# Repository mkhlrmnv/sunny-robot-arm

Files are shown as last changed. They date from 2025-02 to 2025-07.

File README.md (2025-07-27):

# Sunny Robot Arm 🌞🤖

The project is built by Mikhail Romanov and Jaakko Aalto completely from scratch. Only motors, drivers, linear rail and arms aluminum profile were bought, all the rest is custom made by first designing parts in CAD, then manufacturing them using multiple metalworking techniques like CNC milling, water cutting and metal turning or 3D printing for smaller parts.

Project is a precision solar tracking robotic arm system that automatically follows the sun's path throughout the day. This 2-DOF robotic arm mounted on a linear rail uses advanced kinematics calculations to track solar positions while maintaining safety through collision detection. At the end arm has RGB LED lamp that ajust its brightness and color based on the solar position and system status. This features allow robot to simulate effect of the sunlight on office enviroment, which is then used in the Aalto University research to study the impact of natural light on human well-being and productivity in house automation and smart buildings.

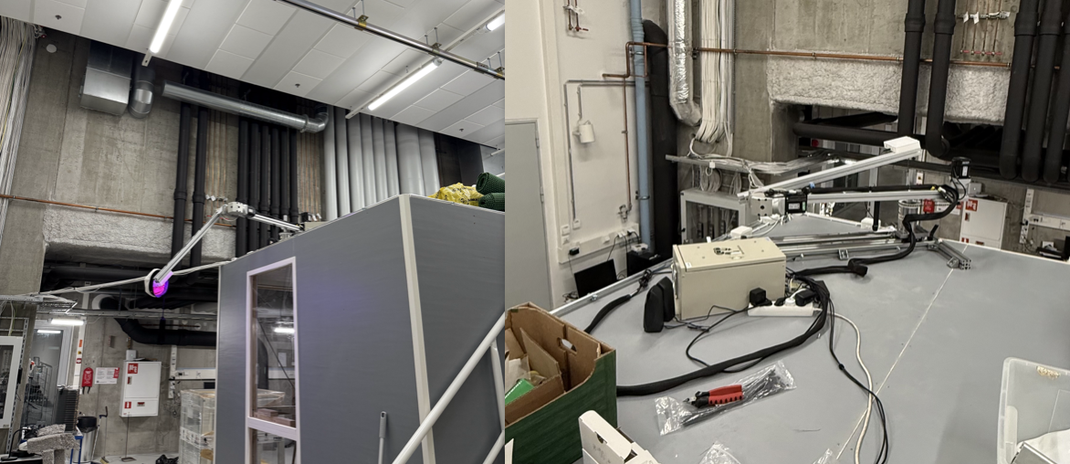
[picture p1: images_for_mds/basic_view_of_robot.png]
Basic view of the robot


### Web Dashboard Features

- Real-time 3D robot visualization while executing pathits brightness and color based on the solar position and system status. This features allow robot to simulate effect of the sunlight on office enviroment, which is then used in the Aalto University research to study the impact of natural light on human well-being and productivity in house automation and smart buildings.

## 🌟 Features

- **Automated Solar Tracking**: Follows the sun's path automatically using astronomical calculations
- **Smart RGB LED Lamp**: WLED-controlled end effector with dynamic color and brightness that can be controlled via web browser, mobile app, or automatically synchronized with robot movements
- **Precise Kinematics**: Forward and inverse kinematics for accurate positioning
- **Safety Systems**: Built-in collision detection and safety boundary enforcement
- **Web Interface**: Real-time control and monitoring via Flask web application
- **Multi-Location Support**: Pre-configured solar paths for Finland and Singapore
- **Warning System**: Warning system with visual and audio alerts
- **Temperature Management**: Automatic cooling system with fan control
- **Manual Control**: Direct motor control for testing and calibration

## 🏗️ Hardware Architecture

### Robotic Arm Components
- **Pontto Joint**: Base rotation motor (spinning joint) controlling the yaw angle
- **Paaty Joint**: Pitch/elevation motor (spinning joint) controlling the pitch angle
- **Linear Rail**: Horizontal positioning system
- **LED Strip**: End effector with RGB LED lamp for visual status feedback via WLED (controllable via web browser, mobile app, or automatically synchronized with robot movements)
- **Cooling Fan**: Temperature management system
- **Limit Switches and Induction Sensors**: Safety and homing sensors

### Technical Specifications
- **Arm lengths**: 
  - Pontto: 835mm
  - Paaty: 905mm
- **Rail Travel**: 731.3mm linear range
- **Joint Angles**: 
  - Pontto: -172° to +188° (360° range)
  - Paaty: ±180° range
- **Precision**: Stepper motor control with gear ratios

## 📁 Project Structure

```
sunny-robot-arm/
├── src/                          # Core application code
│   ├── arm.py                    # Main robot arm controller
│   ├── kinematics_and_safety.py  # Forward/inverse kinematics & collision detection
│   ├── sun_helper.py             # Solar position calculations
│   ├── spinning_joints.py        # Rotational motor control
│   ├── linear_rail.py            # Linear actuator control
│   ├── lamp.py                   # LED control interface
│   ├── cooling.py                # Temperature management
│   └── config.py                 # Hardware configuration constants
│   └── warning.py                # Warning system for audio alerts
├── ui/                           # Web interface
│   ├── main.py                   # Flask web server
│   ├── templates/                # HTML templates
│   └── static/                   # CSS/JS assets
├── paths/                        # Pre-calculated solar paths
├── test/                         # Unit tests
├── documentation/                # Technical documentation
└── sounds/                       # Audio feedback files
```

## 🚀 Quick Start

### Were to start

- **Basic Guide** Basic tutorial on how to use the robot via web interface or API, refer to the tutorial md [here](quick_tutorial.md).
- **Documentation**: Detailed documentation in strucuture of the robot (electrical wirings, class structure, manufacturing process, etc.) can be found in the [documentation](documentation/README.md).

### Hardware used in this project
- Raspberry Pi 4
- Python 3.10
- 2x JT-RD6012 Power Supply (70v x 12.5A)
- 3x Leadshine CS-M23445 stepper motors with Leadshine CS-D808 drivers
- WLED-compatible LED strip (with 144 LEDs/m)
- 2x SN04-N Induction Sensors for homing
- 2x Basic limit switches for linear rail position detection
- A lot other unspecified parts like fan, power supplies and thermal sensor that can be found in wiring diagram

### Cooling System

Automatic temperature management with configurable thresholds:

- Fan activation at 30°C
- Maximum cooling at 60°C
- Temperature logging and alerts

## 📄 License

This project is licensed under the MIT License - see the [LICENSE](LICENSE) file for details.

## 🙏 Acknowledgments

- **pvlib**: Solar position calculations
- **Flask**: Web interface framework  
- **NumPy/SciPy**: Mathematical computations
- **Matplotlib**: Visualization tools
- **RPi.GPIO**: Raspberry Pi hardware control

---

**Built with ❤️ and passion for robotics**

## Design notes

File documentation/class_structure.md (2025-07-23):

# Sunny Robot Arm - Class Structure

## 🏗️ Core Architecture Overview

The project follows a modular architecture with clear separation of concerns:

```
Main Controller (Arm) 
    ├── Motor Controllers (SpinningJoints, LinearRail)
    ├── Visual Feedback (Lamp)  
    ├── Audio System (WarningSound)
    ├── Kinematics Engine (Functions)
    ├── Safety Systems (Functions)
    └── Cooling System (FanController)
```

## 📋 Class Diagram

### 🎮 **Main Controller Classes**

#### **`Arm`** - Primary Robot Controller
```python
class Arm:
    # Properties
    - theta_1: float              # Pontto joint angle (°)
    - theta_2: float              # Paaty joint angle (°) 
    - delta_r: float              # Linear rail position (mm)
    - required_theta_1: float     # Target pontto angle
    - required_theta_2: float     # Target paaty angle
    - required_delta_r: float     # Target rail position
    - current_path: np.array      # Path points to follow
    - current_path_colors: list   # Color data for path visualization
    - iteration: int              # Current path point index
    - duration_per_point: float   # Time per path point
    - shared: Namespace           # Multiprocessing shared state
    
    # Component References
    - motor_paaty: SpinningJoints     # Pitch motor controller
    - motor_pontto: SpinningJoints    # Yaw motor controller  
    - motor_rail: LinearRail          # Linear actuator controller
    - lamp: Lamp                      # LED strip controller
    - warning_sound: WarningSound     # Audio feedback system
    
    # Methods
    + __init__(shared, init_pos, dimensions...)
    + init()                          # Initialize and home all motors
    + shutdown()                      # Safe shutdown procedure
    + init_path(path_file, duration)  # Load solar tracking path
    + move(speeds, check_safety)      # Execute movement to next path point
    + _target_not_set() -> bool       # Check if target is defined
    + _step_towards(attr, target)     # Safe incremental movement
    + _compute_next_target()          # Calculate next path target
    + _clear_target()                 # Reset target after reaching point
    + draw_all(index, ax)             # Visualization for matplotlib
```

### 🔧 **Motor Controller Classes**

#### **`SpinningJoints`** - Rotational Motor Controller
```python
class SpinningJoints:
    # Properties
    - shared: Namespace           # Multiprocessing shared state
    - name: str                   # Motor identifier ("pontto"/"paaty")
    - angle: float                # Current angle (degrees)
    - steps: int                  # Step count from home position
    - step_per_rev: int           # Steps per motor revolution (1600)
    - gear_ratio: float           # Gearbox reduction ratio
    - angle_limit: float          # Maximum rotation range
    - min_delay: float            # Fastest step timing
    - max_delay: float            # Slowest step timing
    
    # Hardware Interfaces
    - pulse: DigitalOutputDevice  # Step pulse pin
    - direction: DigitalOutputDevice  # Direction control pin
    - limit_switch: Button        # Homing sensor
    - limit_event: Event          # Thread-safe sensor state
    
    # Methods
    + __init__(shared, pins, name, ratios...)
    + init_motor(speed)           # Homing sequence with sensor detection
    + step(direction, speed)      # Single step execution
    + move_by_angle(angle, speed) # Relative angular movement
    + move_to_angle(angle, speed) # Absolute angular positioning
    + calc_delay(speed_percent)   # Speed-to-timing conversion
    + reset_position()            # Set current position as zero
    + shutdown()                  # Safe parking position
```

#### **`LinearRail`** - Linear Actuator Controller  
```python
class LinearRail:
    # Properties
    - shared: Namespace           # Multiprocessing shared state
    - distance: float             # Current position (mm)
    - steps: int                  # Step count from home
    - angle: float                # Equivalent angular displacement
    - step_per_rev: int           # Motor steps per revolution
    - gear_ratio: float           # Gear reduction factor
    - pitch: float                # Lead screw pitch (mm/rev)
    - min_delay: float            # Timing limits for speed control
    - max_delay: float
    - stop: bool                  # Limit switch state
    
    # Hardware Interfaces  
    - pulse: DigitalOutputDevice  # Step pulse pin
    - direction: DigitalOutputDevice  # Direction control pin
    - limit_switch: Button        # Position limit sensor
    - limit_event: Event          # Thread-safe limit state
    
    # Methods
    + __init__(shared, pins, mechanical_params...)
    + init_motor(direction)       # Homing to limit switch
    + step(direction, speed, ignore_limit)  # Single step with safety
    + move_by_distance(dist, speed)         # Relative linear movement
    + move_to_distance(dist, speed)         # Absolute positioning
    + calc_delay(speed_percent)             # Speed mapping
    + reset_position()                      # Zero position reference
```

### 🎨 **Feedback Systems**

#### **`Lamp`** - RGB LED Controller
```python
class Lamp:
    # Properties
    - brightness: int             # Overall brightness (0-255)
    - https_url: str              # WLED controller URL
    - red: int                    # Current red component (0-255)
    - green: int                  # Current green component (0-255) 
    - blue: int                   # Current blue component (0-255)
    - effect: int                 # WLED effect index (0=solid, 1=blink...)
    - speed: int                  # Effect speed (milliseconds)
    
    # Methods
    + __init__(brightness, https_url)
    + set_brightness(level)       # Control overall brightness
    + set_to_effect(r, g, b, effect, speed)  # Generic effect control
    + set_to_solid(r, g, b)       # Solid color mode
    + set_to_blink(r, g, b, speed)           # Blinking warning mode
    + _send_to_wled(json_data)               # HTTP API communication
```

#### **`WarningSound`** - Audio Alert System
```python
class WarningSound:
    # Properties
    - _stop: threading.Event      # Thread synchronization
    - _thread: Thread             # Background playback thread
    - _is_playing: bool           # Current playback state
    
    # Methods
    + __init__(audio_file)        # Load sound file via pygame
    + start()                     # Begin looped playback
    + stop()                      # Stop playback and cleanup
    + _play_loop()                # Internal playback thread
```

#### **`FanController`** - Thermal Management
```python
class FanController:
    # Properties
    - sensor: W1ThermSensor       # DS18B20 temperature sensor
    - fan: PWMOutputDevice        # PWM-controlled cooling fan
    - min_temp: float             # Fan activation threshold (°C)
    - max_temp: float             # Full-speed threshold (°C)
    - latest_reading: dict        # Current temperature/speed data
    
    # Methods
    + __init__(fan_pin, min_temp, max_temp)
    + map_temp_to_speed(temp)     # Temperature to PWM conversion
    + run(verbal, interval)       # Main control loop
    + shutdown()                  # Safe fan stop and GPIO cleanup
```

### 🧮 **Utility Functions** (Functional Programming)

#### **Kinematics Module** (`kinematics_and_safety.py`)
```python
# Core Kinematics Functions
+ inverse_kinematics(x, y, z, **params) -> List[Tuple[float, float, float]]
    # Solve joint angles for target position
    
+ forward_kinematics(theta1, theta2, delta_r, **params) -> np.array
    # Calculate all joint positions from angles
    
+ choose_solution(solutions, current_state) -> Tuple[float, float, float]
    # Select optimal solution from IK candidates

# Safety and Collision Detection
+ check_solutions_safety(solution, safety_boxes) -> bool
    # Verify movement doesn't cause collisions
    
+ draw_robot(ax, points) -> None
    # 3D visualization of robot configuration
    
+ draw_all_safety_boxes(ax) -> None
    # Render collision boundaries
```

#### **Solar Path Module** (`sun_helper.py`)
```python
# Solar Position Calculations
+ get_sun_path_finland(R, lat, lon, timezone) -> Tuple[np.array, np.array, np.array]
    # Generate solar tracking path for Finland
    
+ get_sun_path_singapore(R, lat, lon, timezone) -> Tuple[np.array, np.array, np.array]
    # Generate solar tracking path for Singapore
    
+ alt_to_color(altitude_deg) -> Tuple[int, int, int]
    # Map solar altitude to RGB color temperature
    
+ jsonify_path(path, colors, filename) -> None
    # Serialize path data to JSON
    
+ un_jsonify_path(filename) -> Tuple[np.array, np.array]
    # Load path data from JSON
```

### 🌐 **Web Interface** (`ui/main.py`)

#### **Flask Application**
```python
# Global State
- app: Flask                      # Web server instance
- arm: Arm                        # Robot controller reference
- shared: Namespace               # Multiprocessing shared state
- motor_lock: Lock                # Thread synchronization
- angles_per_key: int             # Manual control step size

# Core Routes
@app.route('/')                   # Main dashboard
@app.route('/manual')             # Manual control interface
@app.route('/move_arm')           # Primary API endpoint
@app.route('/points')             # Current robot position data
@app.route('/path_points')        # Active path visualization data  
@app.route('/cooling_info')       # Temperature monitoring

# Process Management Functions
+ start_arm(func, args)           # Execute robot function in subprocess
+ stop_arm()                      # Terminate active robot processes
+ is_arm_running() -> bool        # Check subprocess status
+ start_arm_and_wait(func, args) -> int  # Blocking execution with return code
```

## 🔄 **Data Flow Architecture**

### **Multiprocessing Communication**
```python
# Shared State Object (Manager.Namespace)
shared = {
    'theta_1': float,        # Current pontto angle
    'theta_2': float,        # Current paaty angle  
    'delta_r': float,        # Current rail position
    'path_it': int,          # Path iteration counter
    'timer': float,          # Last movement timestamp
    'path': np.array         # Active path points
}
```

### **Control Flow**
1. **Web Interface** receives user commands
2. **Flask API** validates parameters and safety
3. **Process Manager** spawns subprocess for robot control
4. **Arm Controller** coordinates motor movements
5. **Motor Controllers** execute precise positioning
6. **Feedback Systems** provide visual/audio status
7. **Shared State** maintains synchronization across processes

### **Safety Integration**
- All movements validated through **inverse kinematics**
- **Collision detection** prevents unsafe configurations
- **Joint limits** enforced at motor controller level
- **Emergency stop** capability via web interface
- **Homing sequences** ensure accurate position reference

## 📊 **Key Design Patterns**

### **Composition over Inheritance**
- `Arm` class aggregates motor controllers rather than inheriting
- Enables flexible configuration and testing
- Clear component boundaries and responsibilities

### **Shared State Pattern**  
- `multiprocessing.Manager.Namespace` for inter-process communication
- Thread-safe access to robot state across web server and control processes

### **Observer Pattern**
- GPIO limit switches trigger events for safety monitoring
- Real-time status updates to web interface

This architecture provides a robust, safe, and extensible foundation for precise solar tracking while maintaining clear separation between hardware control, safety systems, and user interfaces.

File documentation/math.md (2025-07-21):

# Explanations of the math used in this project

## Link to the notebook
You can find the explanations of the math used in this project in the following notebook:
[GoodNotes Notebook](https://share.goodnotes.com/s/Pw0ZdXbuqwoWTpLTJgBrya)

## Catalog of the notebook
- **Config**: This sections explains variables used in the project, such as names of the specific parts of the robot.
- **Forward Kinematics**: This function calculates the position and orientation of the all 6 points of the arm based on the joint angles.
- **Inverse Kinematics**: This function calculates the joint angles required to reach a specific position in space.
- **Get Suns Position**: This function calculates the position of the sun based on the provided time and date and adjust all the points to be reachable by the arm.

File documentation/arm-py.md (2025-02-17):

### Explanation of `calc_join_angles` Function

The `calc_join_angles` function calculates the joint angles (`theta1` and `theta2`) for a robotic arm based on the desired position (`pos`). The function assumes that the robotic arm has two segments (`arm1` and `arm2`) and calculates the angles required to reach the given position.

#### Calculations

#### Theta2 Calculation

1. **Calculate the difference in the z-axis (`delta_z`)**:
    ```python
    delta_z = self.base_pos.z - pos.z
    ```

2. **Calculate the horizontal distance ([alpha](http://_vscodecontentref_/0))**:
    ```python
    alpha = np.sqrt(self.arm2_length**2 - delta_z**2)
    ```

3. **Calculate the angle [theta3](http://_vscodecontentref_/1)**:
    ```python
    theta3 = np.arccos(delta_z / self.arm2_length)
    ```

4. **Calculate the angle [theta2](http://_vscodecontentref_/2)**:
    ```python
    theta2 = theta3 + np.deg2rad(90)
    ```

### Theta1 Calculation

1. **Calculate the difference in the y-axis ([delta_y](http://_vscodecontentref_/3))**:
    ```python
    delta_y = self.base_pos.y - pos.y
    ```

2. **Calculate the angle [theta1](http://_vscodecontentref_/4)**:
    ```python
    theta1 = np.arccos(delta_y / (self.arm1_length + alpha))
    ```

#### Return Value

The function returns a tuple containing the calculated angles ([theta1](http://_vscodecontentref_/5) and [theta2](http://_vscodecontentref_/6)):
```python
return (theta1, theta2)
```

#### Description on paper
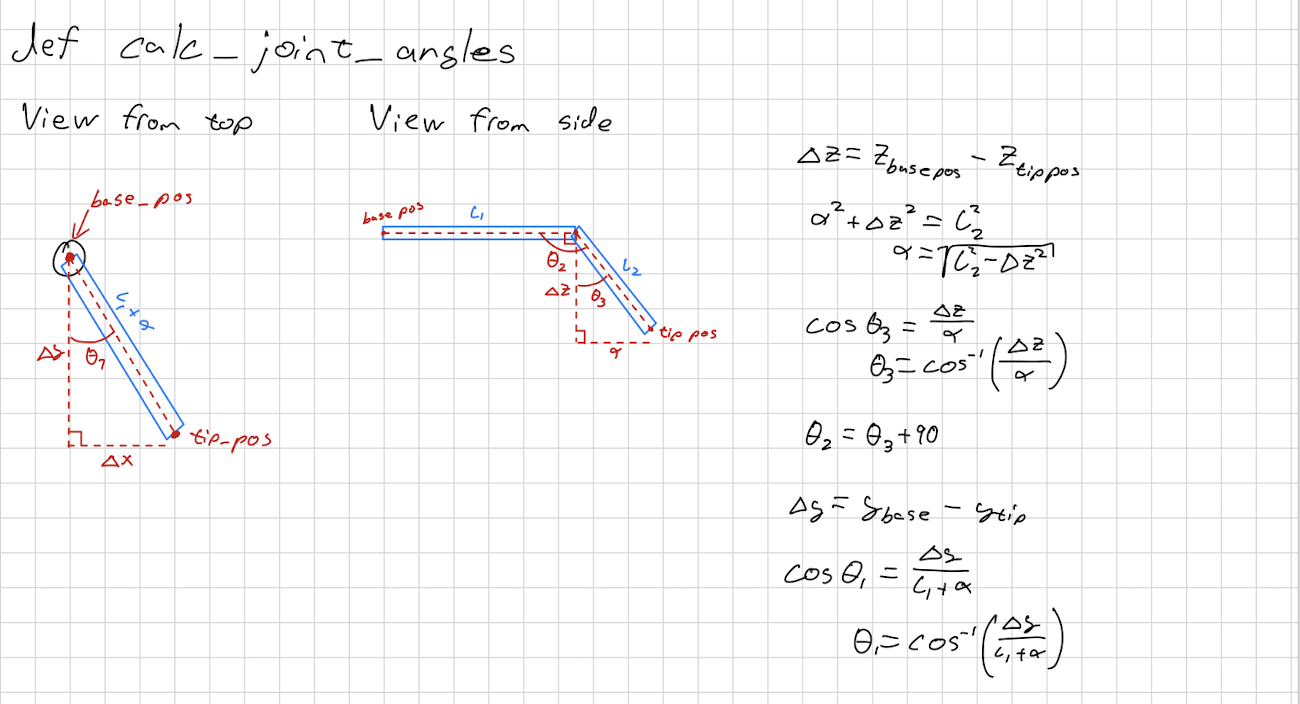
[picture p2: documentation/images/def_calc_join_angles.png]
Description of the image


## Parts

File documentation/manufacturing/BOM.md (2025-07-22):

# Bill of Materials

This project uses the following components:

| Part | Quantity | Link |
|---|---|---|
| Switching power supply Joy-IT JT-RD6012-NT (56–71V, 12.5A) | 2 | [link](https://www.rocketronics.de/shop/en/JT-RD6012-NT.html) |
| Driveset 1-axis with CS-D808 and 4.5Nm closed loop motor CS-M23445 | 3 | [link](https://www.rocketronics.de/shop/en/product_info.php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) |
| EG Series Planetary Gearbox (5:1, 15 arc-min, for Nema 34) | 2 | [link](https://www.omc-stepperonline.com/eg-series-planetary-gearbox-gear-ratio-5-1-backlash-15-arc-min-for-nema-34-stepper-motor-eg34-g5) |
| RYG Series Right Angle Planetary Gearbox (5:1, 10 arc-min, for Nema 34) | 1 | [link](https://www.omc-stepperonline.com/ryg-series-right-angle-planetary-gearbox-gear-ratio-5-1-backlash-10arc-min-for-nema-34-stepper-motor-ryg34-g5) |
| Raspberry Pi 5 | 1 | [link](https://www.power.fi/tietotekniikka/tietokonekomponentit/mikrokontrollerit/raspberry-pi-5-4-gt-yhden-piirilevyn-tietokone/p-3325901/) |
| Raspberry Pi power supply | 1 | [link](https://www.power.fi/tietotekniikka/tietokonekomponentit/mikrokontrollerit/raspberry-pi-5-virtalahde/p-3325903/) |
| Machined ballscrew SFU2010–1500mm with nut | 1 | [link](https://greenlab.fi/tuote/tyostetty-kuularuuvi-sfu2010-1500mm-mutterilla/) |
| Ballscrew support bearing BK15 | 1 | [link](https://greenlab.fi/tuote/kuularuuvin-tukilaakeri-bk15/) |
| Ballscrew support bearing BF15 | 1 | [link](https://greenlab.fi/tuote/kuularuuvin-tukilaakeri-bf15/) |
| Ballnut housing DSG20H | 1 | *(no link provided)* |
| Aluminium profile 45×45 L, 1m | 1 | [link](https://greenlab.fi/tuote/alumiiniprofiili-45x45-l/) |
| Aluminium profile 45×45 light, 1m | 1 | [link](https://greenlab.fi/tuote/alumiiniprofiili-45x45-kevyt/) |
| Linear rail HGR25R-C (1m) | 2 | [link](https://greenlab.fi/tuote/lineaarijohde-hgr25r-c/) |
| Linear block HGW25HA Z0C | 2 | [link](https://greenlab.fi/tuote/lineaarikelkka-hgw25ha-z0c/) |
| Rail end stopper HG25 | 4 | [link](https://greenlab.fi/tuote/pysaytinpaaty-hg25/) |
| Jaw coupling MM2 40 D14/12 | 1 | [link](https://greenlab.fi/tuote/sakarakytkin-mm2-40-d14-17/) |

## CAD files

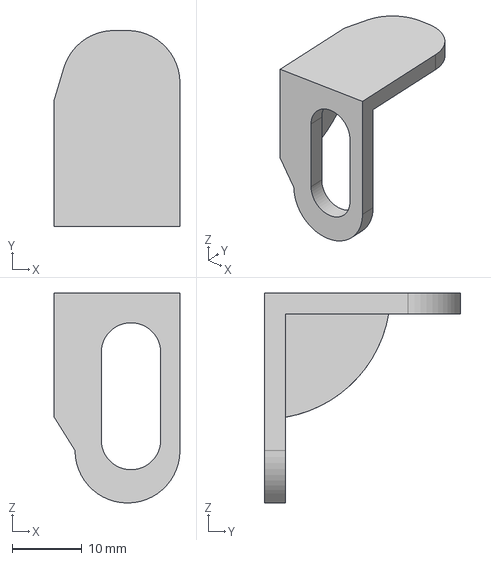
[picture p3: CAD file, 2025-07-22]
documentation/manufacturing/Corner safeguard.step
18.0 x 28.0 x 30.0 mm

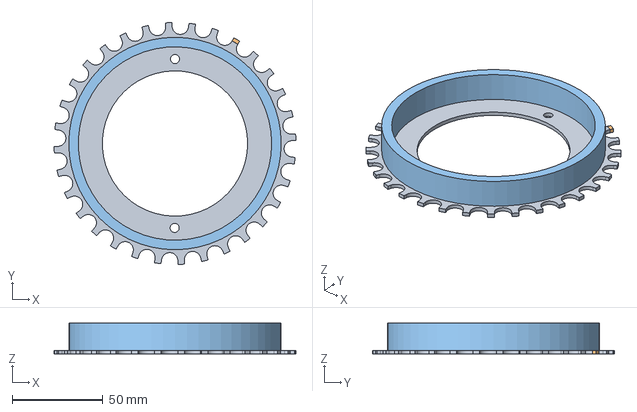
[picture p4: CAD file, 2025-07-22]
documentation/manufacturing/Gears/Big gear.step
133.3 x 133.3 x 17.0 mm

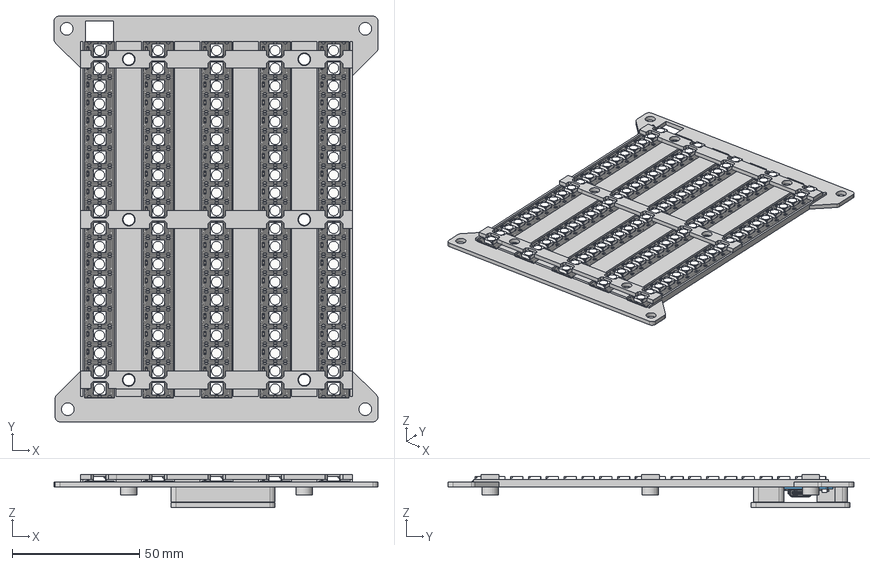
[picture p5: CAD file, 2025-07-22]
documentation/manufacturing/Lamp/STL files/LED base (base).step
127.3 x 159.5 x 13.0 mm
SMD x 100
WS2812 LED Chip x 100
PCB Strip x 100
Pads x 100
esp kansi
USB C + USB A 3.1.stp
main board
palkki x 3

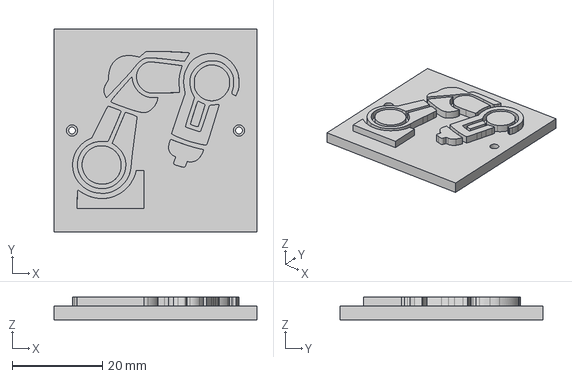
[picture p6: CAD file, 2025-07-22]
documentation/manufacturing/Logos/logo positive.step
45.0 x 45.0 x 5.00 mm

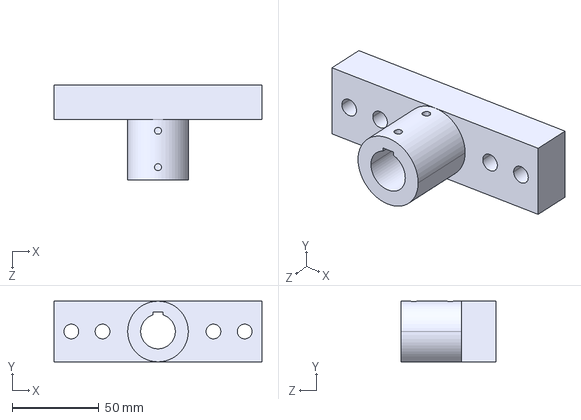
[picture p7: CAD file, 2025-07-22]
documentation/manufacturing/Motor attachers/Bevel gear attacher (to greenlab profile).STEP
120.0 x 35.0 x 55.0 mm

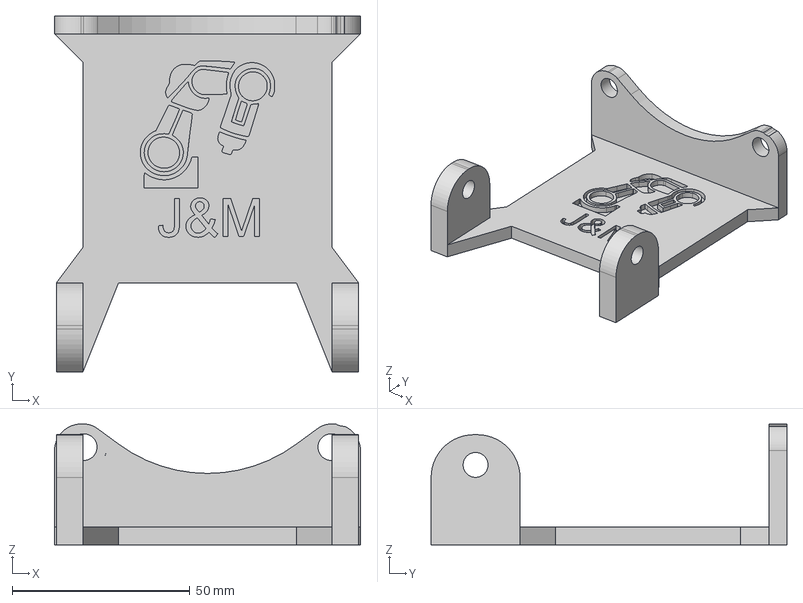
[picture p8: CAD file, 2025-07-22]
documentation/manufacturing/Motor attachers/Linear motor/Linear motor connector to robot's base.step
86.0 x 100.0 x 34.0 mm

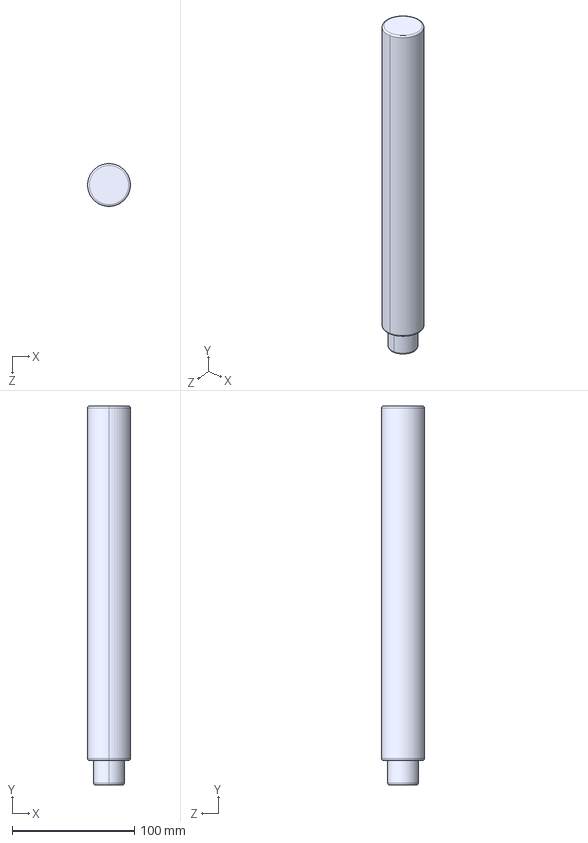
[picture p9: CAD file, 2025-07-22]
documentation/manufacturing/Pönttö parts/Axis of rotation.STEP
35.0 x 310.0 x 35.0 mm

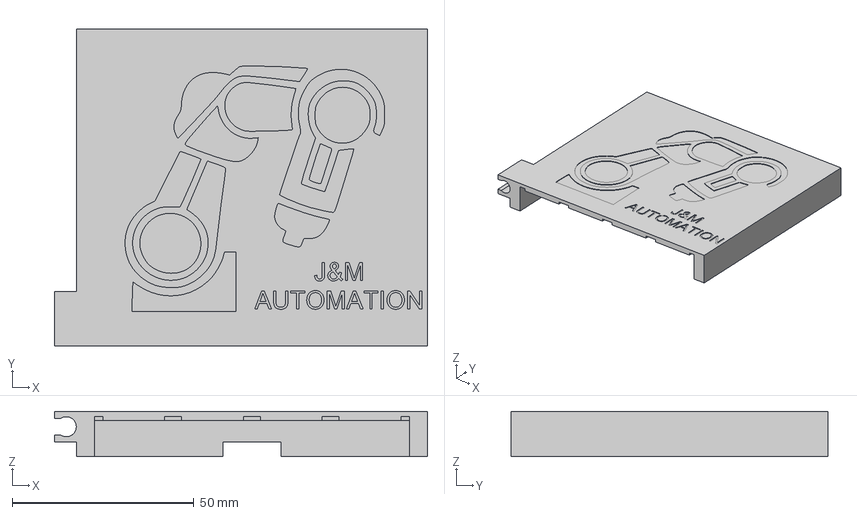
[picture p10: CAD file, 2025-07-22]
documentation/manufacturing/Random holders/Box for USB extension cabse (cover).step
102.7 x 87.2 x 12.5 mm

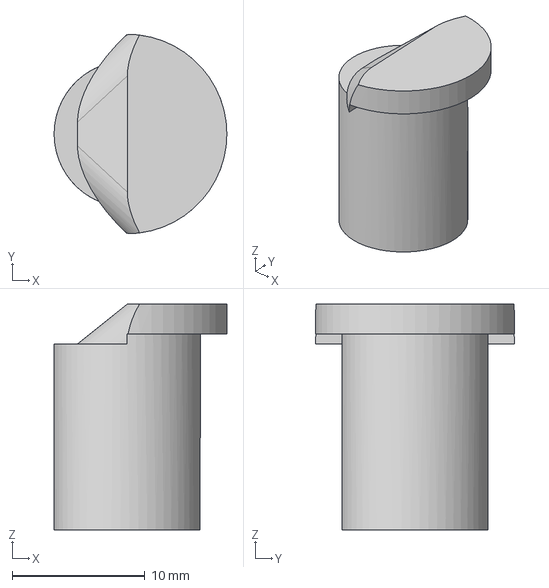
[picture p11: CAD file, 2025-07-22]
documentation/manufacturing/Sensors/Linear init/Pin for limit switch holder.step
13.0 x 15.0 x 17.0 mm

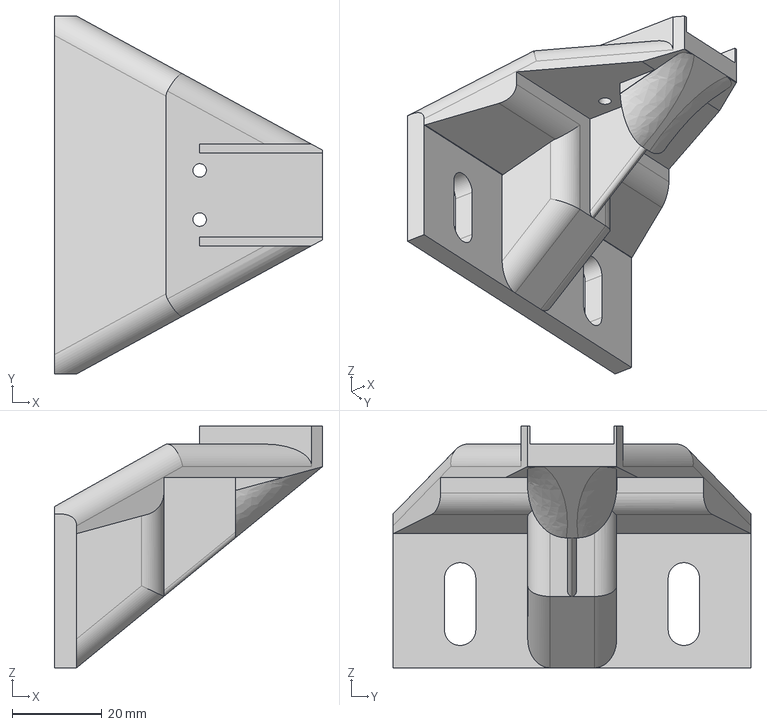
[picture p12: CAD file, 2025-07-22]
documentation/manufacturing/Sensors/Paaty init/Paaty motor init sensor holder.step
60.0 x 80.0 x 54.0 mm

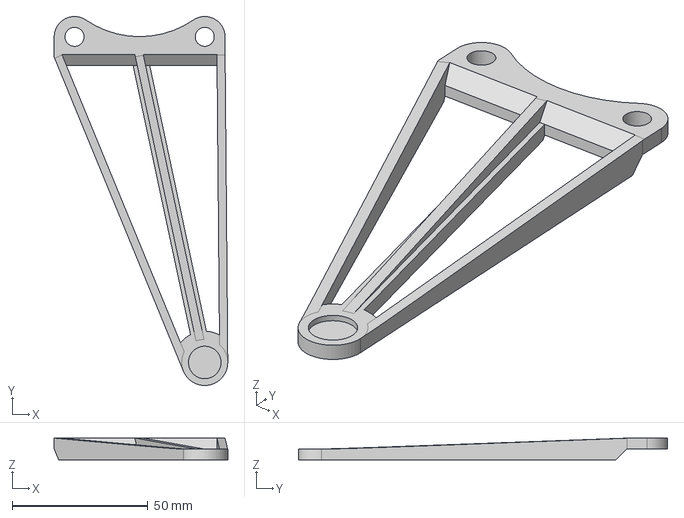
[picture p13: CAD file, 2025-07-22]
documentation/manufacturing/Sensors/Pontto init/Melta holder for pontto motor init.step
64.0 x 136.0 x 8.00 mm

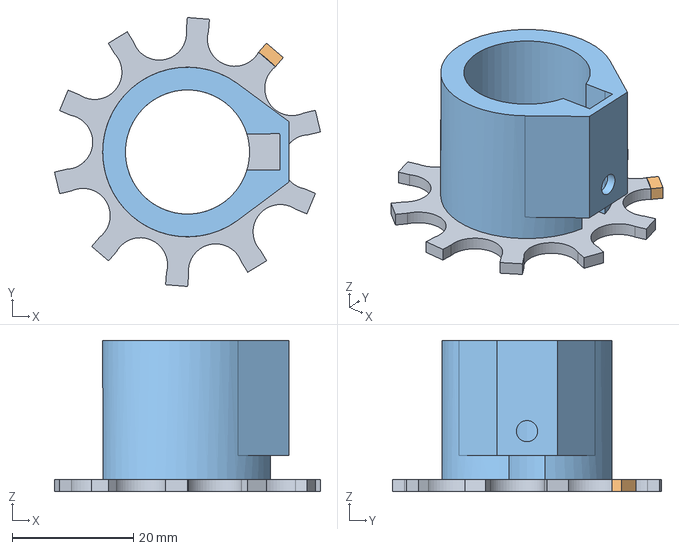
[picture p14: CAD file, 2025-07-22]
documentation/manufacturing/Gears/Small gear.step
43.9 x 44.4 x 25.0 mm

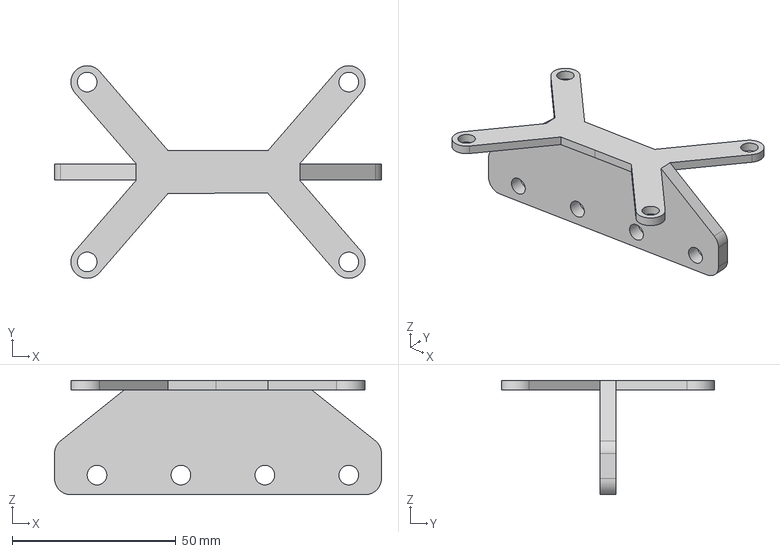
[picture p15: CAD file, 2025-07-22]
documentation/manufacturing/Lamp/STL files/Lamp attacher (general).step
100.0 x 65.0 x 35.0 mm
yleinen pidike

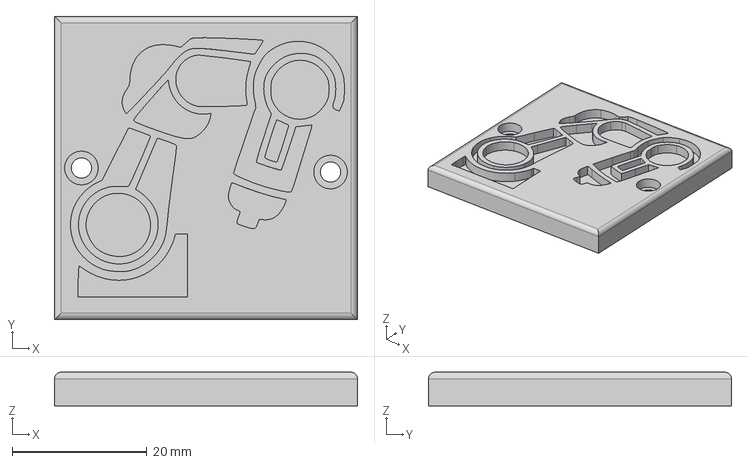
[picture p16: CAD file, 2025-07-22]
documentation/manufacturing/Logos/logo negative.step
45.0 x 45.0 x 5.00 mm

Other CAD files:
documentation/manufacturing/Motor attachers/Direct gear attacher (to greenlab profile).STEP
documentation/manufacturing/Motor attachers/Linear motor/Linear motor holder.SLDPRT
documentation/manufacturing/Original idea.step
documentation/manufacturing/Pönttö parts/Base pipe.STEP
documentation/manufacturing/Corner safeguard.f3d
documentation/manufacturing/Gears/Big gear.f3d
documentation/manufacturing/Gears/Small gear.f3d
documentation/manufacturing/Lamp/LED strip base.f3z
documentation/manufacturing/Lamp/STL files/Base box of the lamp.step
documentation/manufacturing/Lamp/STL files/Cover of the lamp.step
documentation/manufacturing/Lamp/STL files/LED base (esp cover).step
documentation/manufacturing/Lamp/STL files/LED base (holder piece).step
documentation/manufacturing/Lamp/STL files/Lamp attacher (greenlab profile).step
documentation/manufacturing/Logos/logo negative.f3d
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

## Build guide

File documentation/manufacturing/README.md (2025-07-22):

# Manufacturing Documentation

This folder contains all the design files, documentation, and manufacturing specifications for the custom-designed mechanical components of the sunny-robot-arm project. All parts were designed and manufactured in-house to meet the specific requirements of the solar tracking robotic system.

## Contents Overview

### Design Files
- **Original CAD Models**: Fusion 360 (.f3d) or Solidworks (.sldprt) 
- **Exported files** STEP (.step) or STL (.stl)

### Component Categories

We tried adding all the basic components, but without assemblies that would showcase the whole robot / other big components, as they require a lot of files that we didn't feel necessary to be added to this repo. For more details, you can contact us and we will provide you with the files.

#### Core Structural Components
- **Bearing Housing**: Custom housing for rotational axis bearings
- **Base Plate**: Main platform connecting linear rails adn the robot's rotational axis

#### Gearing System
- **Big Gear & Small Gear**: Custom gear set for movement around z-axis

#### Motor Mounting Hardware
- **Motor Attachers**: Direct and bevel gear attachment solutions
- **Profile Fasteners**: Aluminum profile connection hardware
- **Linear Motor Components**: Specialized mounting for linear motion system

#### Sensor & Electronics Housing
- **Sensor Mounts**: Precision positioning for limit switches and sensors
- **Cable Management**: Routing and protection for electrical connections

#### Lamp Assembly
- **LED Lamp Box**: Custom fully 3d printable lamp
- **LED Strip Base**: Mounting platform for LED strips

#### Extras
- **Corner Safeguard**: Little part to avoid hitting metal on metal when switching the power off

## Mechanical Design

The robot has 3 degrees of freedom to move a light source in front of two windows simulating the sun. The robot uses three NEMA34 closed loop stepper motors and is controlled with a RaspberryPi 5. The robot sits on a pair of self-cut 1m long linear rails driven by 1.5m long ball screw enabling the robot to reach both windows. On top of the linear rail is a metal platform and a self-designed housing for two bearings. The bearings compensate the axial and radial torque on the rotating axis of the robot.

### The Robot's Degrees of Freedom:
1. **Linear Rail**: Horizontal translation between windows
2. **Horizontally Rotating Axis**: Base rotation for positioning
3. **Vertically Rotating Arm**: Elevation control for sun angle simulation

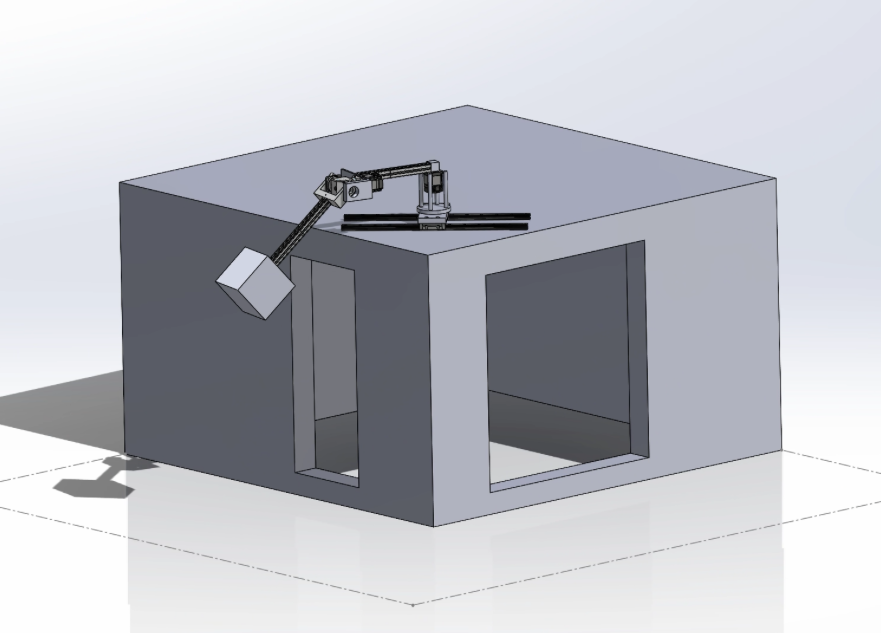
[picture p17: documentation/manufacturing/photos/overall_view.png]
Overview of the CAD Assembly


### Design and Manufacturing of the Housing for Bearings

The final design for the rotational axis and the housing for bearings was achieved after multiple iterations. The driving factors were available material and manufacturing capabilities at Aalto Design Factory (DF). A suitable material pipe was found from DF which affected the design and sizing for bearings and determined the dimensions for the housing.

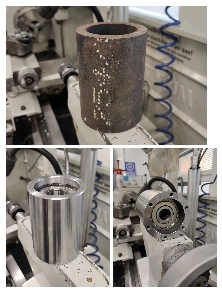
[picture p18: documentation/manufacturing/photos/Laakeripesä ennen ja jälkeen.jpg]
Making of the bearing housing


We wanted to make assembly and disassembly of the housing as easy as possible and ended up with the final design in which all parts were pushed in place from the top side with no hard to reach screws etc. The assembly consists of two bearings and three lock rings. The CAD assembly section view of the housing visualizes the assembly.

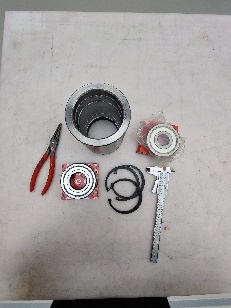
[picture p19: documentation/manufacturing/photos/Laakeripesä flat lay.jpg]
De-assembled housing of bearing


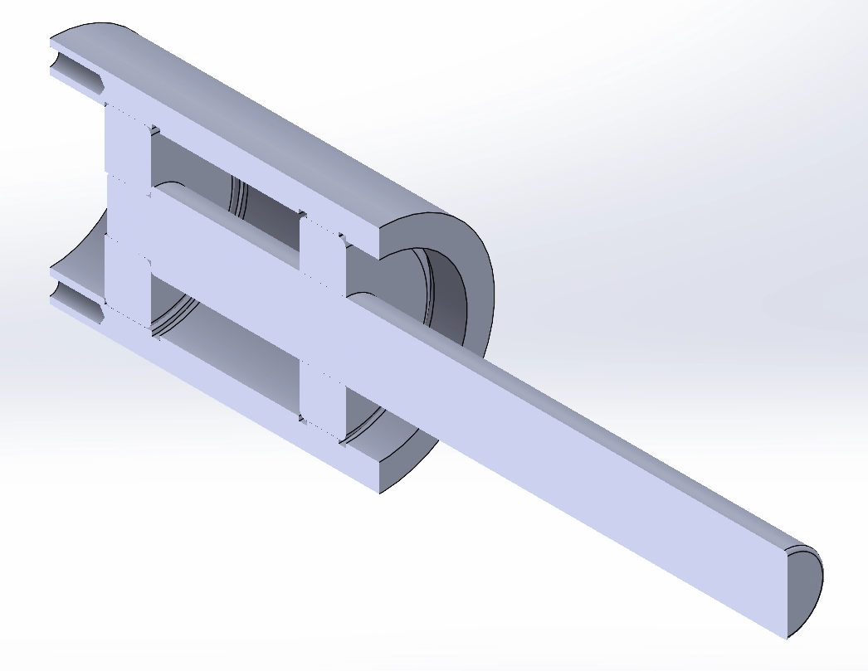
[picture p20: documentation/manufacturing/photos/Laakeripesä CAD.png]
CAD design of bearing housing


### Linear Assembly

For linear motion, the base plate was designed to connect linear rails, ball screw, and the housing of the bearings. This part was made from a piece of metal found in the basement of the DF, and was CNC'd for our needs. The 3D design includes mounting points for all critical components with precise tolerances for proper alignment.

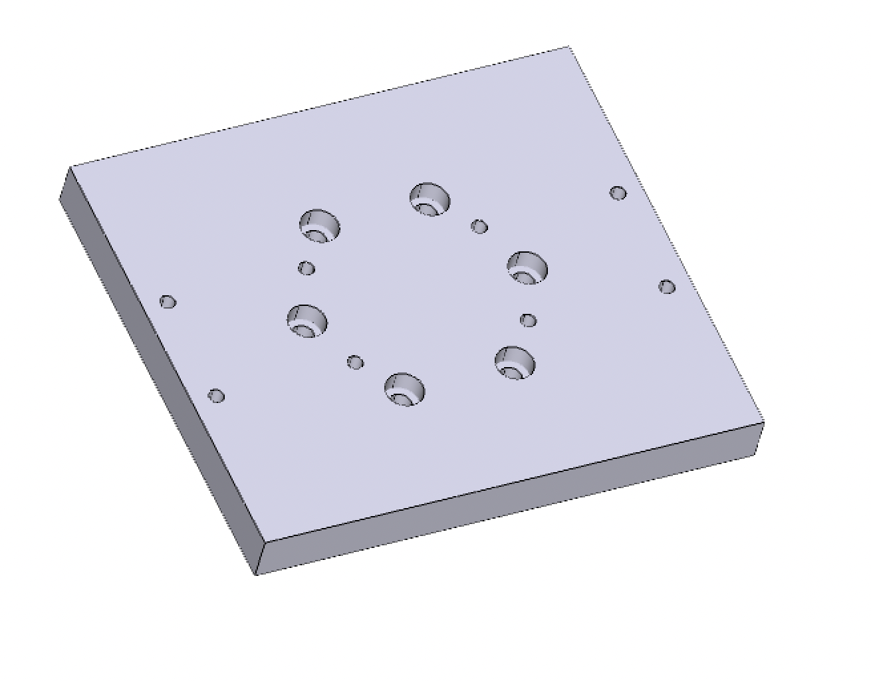
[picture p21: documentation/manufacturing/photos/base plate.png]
CAD view of baseplate


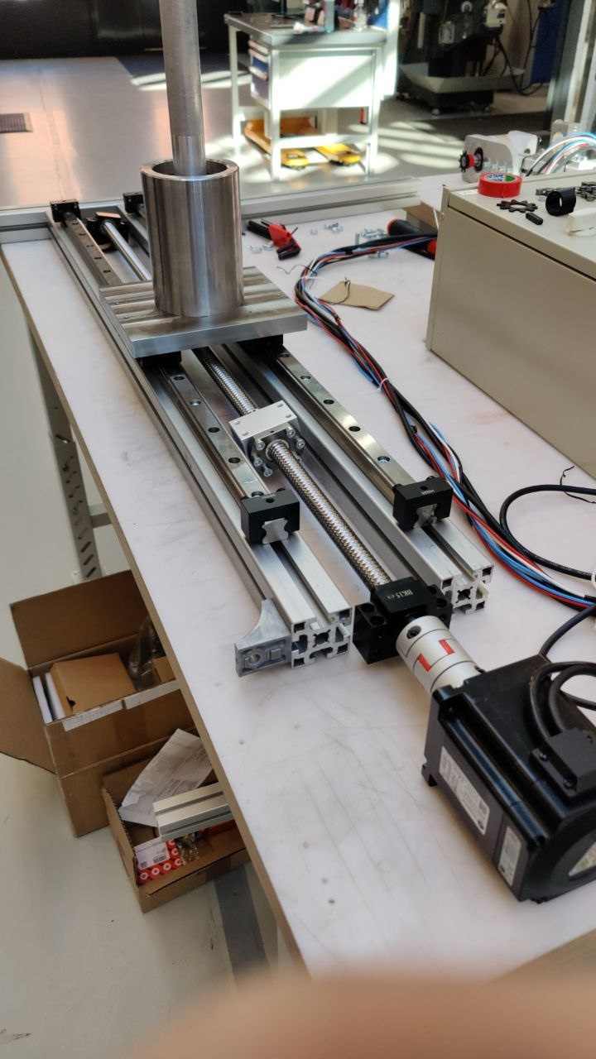
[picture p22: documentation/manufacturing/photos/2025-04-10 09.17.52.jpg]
View of final linear assembly


### Holder Piece for the Motors

Two of the motors were directly mounted to an aluminum profile, so they needed a piece that would attach them. As a bonus from ordering the same motors, we had an advantage of designing one piece that would suit both motors. The part was made from a piece of metal and water cut to our dimensions, ensuring precise fitment and robust mounting.

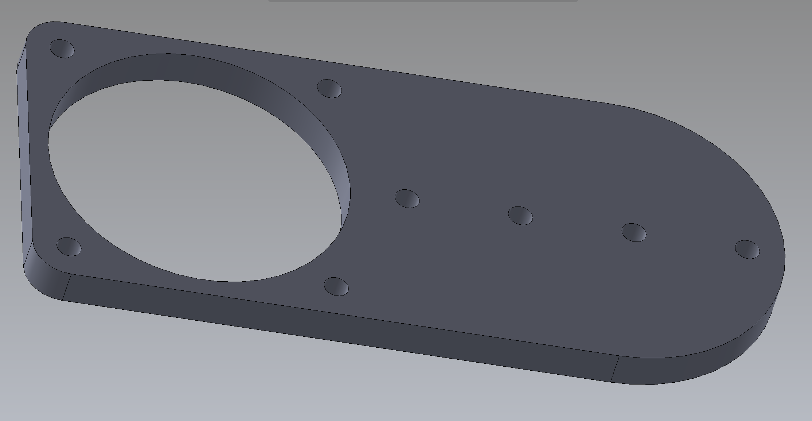
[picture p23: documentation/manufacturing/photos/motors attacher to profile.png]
CAD view of motor attachers


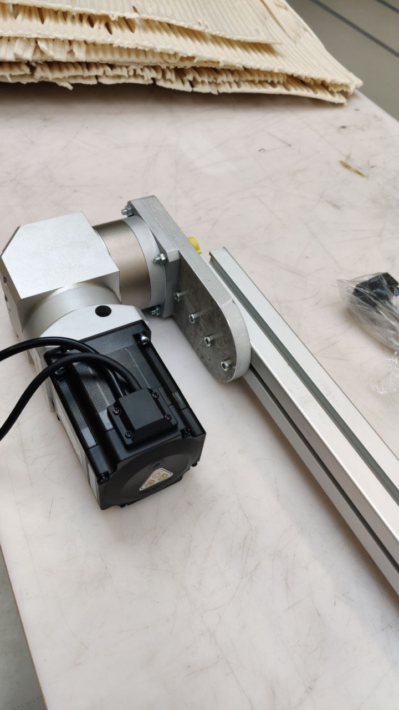
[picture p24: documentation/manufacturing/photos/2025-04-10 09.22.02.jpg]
View of motor beeing attached to profile


### Profile Fastening to Bearing Housing

Finally, after designing the parts to attach the motors to the aluminum profile, the profile itself needed to be connected to a bearing housing to complete the construction of the first two degrees of freedom (2-DOFs). A special piece was designed for this purpose—it attaches to the profile using M8 screws and T-nuts.

Attaching the piece to the axle coming out of the housing was a bit trickier. The chosen solution was to machine a hole slightly larger than the axle's diameter and then clamp the piece onto the axle using an additional screw.

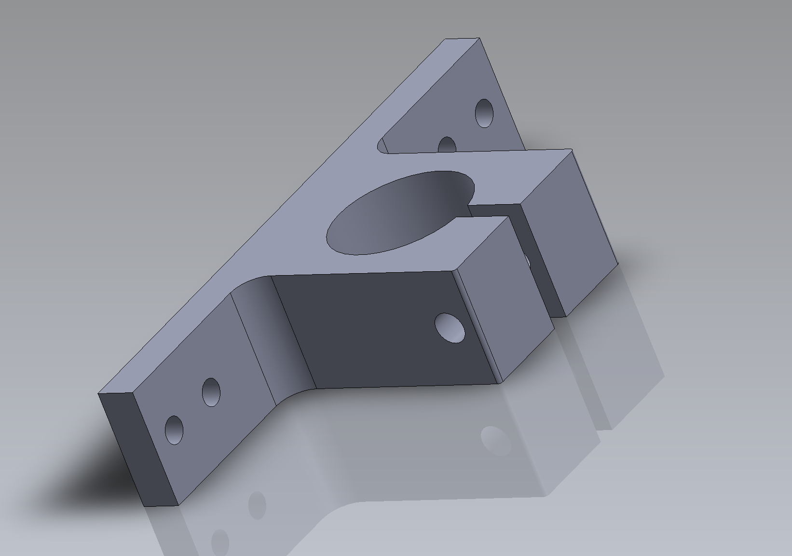
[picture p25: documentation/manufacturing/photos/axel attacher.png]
CAD view of axle attacher


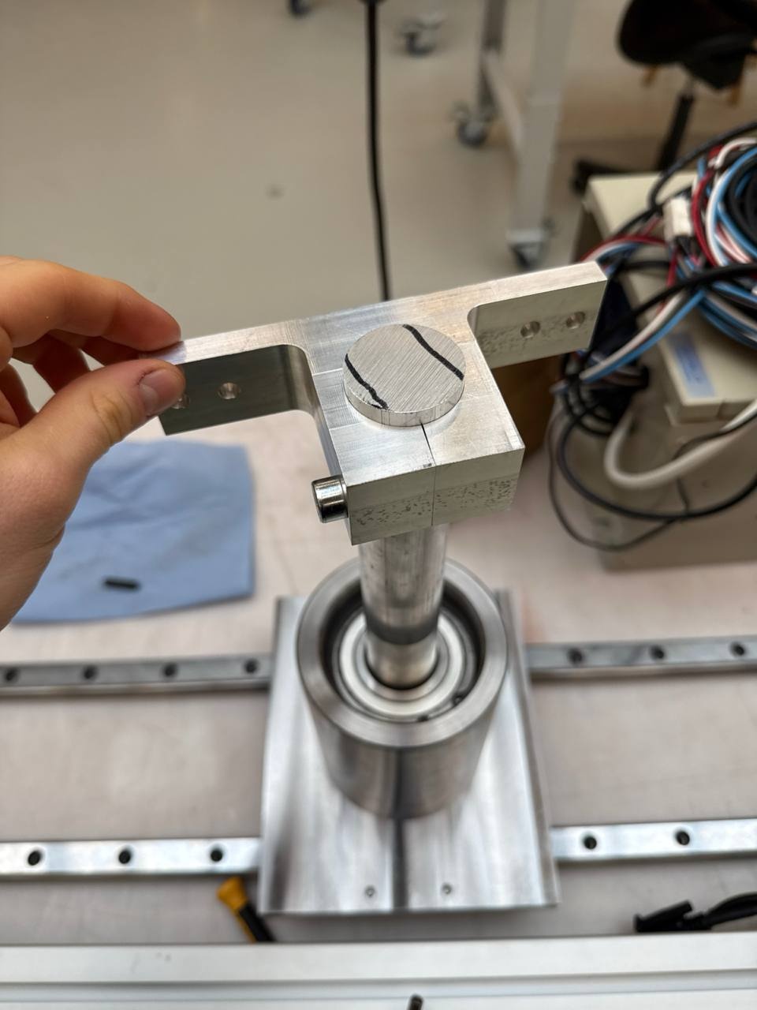
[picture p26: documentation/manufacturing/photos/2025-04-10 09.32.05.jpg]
View of final product:)


### Final Assembly
Final assembly was successful, and "too good" to our surprise. Every piece fit together immediately without the need to adjust or to remake any of them. Additionally, the housing bearing was designed in such a fashion that it compensated all the possible torsions, so the profile could be rotated around the axile with only a pinky, although the total weight of that piece is close to 20kg. 

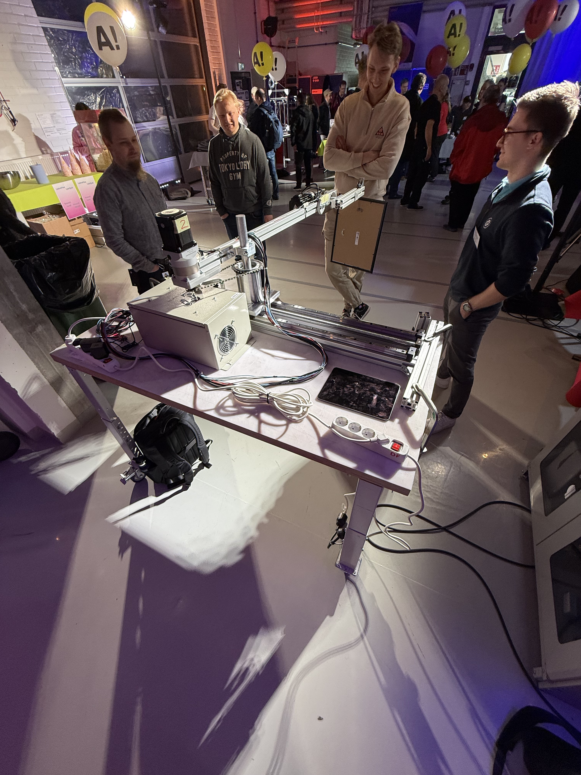
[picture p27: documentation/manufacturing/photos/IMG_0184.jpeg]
View of final product being showcased


## Manufacturing Process

### Design Philosophy
- **Modular Design**: All components designed for easy assembly/disassembly
- **Material Optimization**: Designs adapted to available materials at Aalto Design Factory
- **Manufacturing Constraints**: Parts designed within the capabilities of available equipment

### Manufacturing Methods Used
- **CNC Machining**: Precision parts requiring tight tolerances
- **Water Jet Cutting**: Complex profiles and motor mounting plates
- **3D Printing**: Rapid prototyping and non-structural components
- **Manual Machining**: Custom modifications and final fitting

## File Organization

```
Manufacturing/
├── BOM.md                          # Bill of outside the house Materials
├── README.md                       # Documentation
├── Corner safeguard.f3d/.step      # Safety housing components
├── Original idea.f3d/.step         # Initial concept designs
├── Gears/                          # Transmission components
│   ├── Big gear.f3d/.step
│   └── Small gear.f3d/.step
├── Lamp/                           # Light source assembly
│   ├── LED Lamp.f3z
│   ├── LED strip base.f3z
│   └── STEP files/                  # 3D printable components
├── Logos/                          # Branding and identification
├── Motor attachers/                # Motor mounting hardware
├── Pönttö parts/                   # Bearing housing components
├── Random holders/                 # Miscellaneous mounting hardware
├── Screw drive attachers/          # Linear motion components
└── Sensors/                        # Sensor mounting solutions
```

## Technical Specifications

### Materials Used
- **Aluminum Profiles**: Structural framework
- **Steel Plates**: Base plates and motor mounts
- **PLA / PETG Filaments**: 3D printed components
- **Precision Bearings**: High-quality rotational support

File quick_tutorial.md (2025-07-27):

# Quick Tutorial

This tutorial will guide you through the basics of using the Sunny Robot Arm.

## Getting Started

### Basics

Once powering the system (turning electricity on), rasperry pi will boot and automatically start the server. You can access the web interface by navigating to `http://...:5000` in your web browser. Also make sure that your computer is connected to the lab network '...' or you are using stationary computer in the lab.

Credentials to connect to correct network are:
- name: '...'
- password: '...'

Booting up usually takes about 30 seconds, so please be patient:)

### Terminology

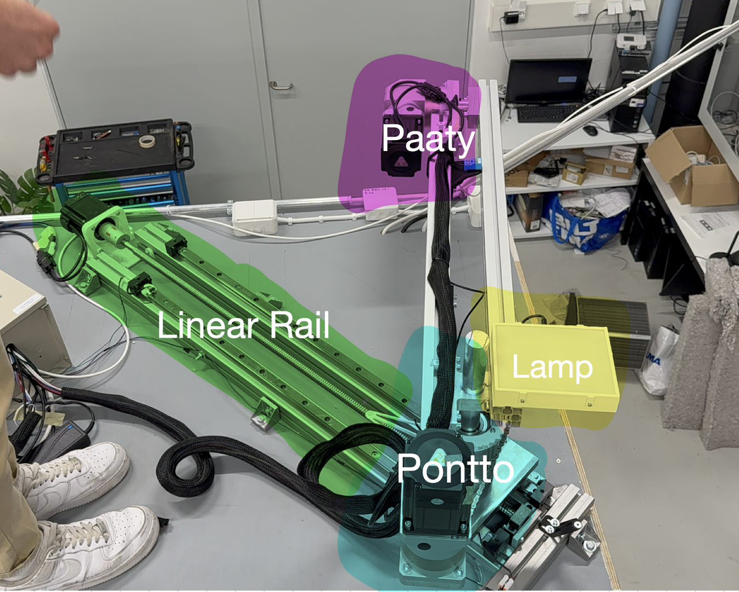
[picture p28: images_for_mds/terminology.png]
Terminology


### Troubleshooting

If after few minutes you still cannot acces the web interface, you have to ssh into the raspberry to manually start the server:

1. Connect to '...' network or use a stationary computer in the lab.
2. Open a terminal on your computer.
3. Type `ssh raspi@raspi.local` and press Enter.
4. Enter the password `...` when prompted.
5. Once logged in, you have to kill all python processes or verify that none are running. You can do this by typing the following command:

```bash
sudo pkill -f python
```

To verify that none are running, run:
```bash
ps aux | grep python
```
If you see any python processes listed, you can kill them using:
```bash
sudo kill <PID>
```

6. After ensuring no python processes are running, start the server by typing:
```bash
cd ~/Desktop/sunny-robot-arm
python -m ui.main
```

7. Wait for the server to start, which may take a few seconds.
8. If none errors occur, follow the instructions in the "Basics" section to access the web interface.

### Alternative Controlling Methods

#### Manual Control via Terminal

If for some reason you want to run manual control straight from the terminal of raspberry pi, you have to first ssh into the raspberry pi as described above. Then you can run the manual control script by typing:

```bash
cd ~/Desktop/sunny-robot-arm
python src/wsd_control.py
```

This will start the script that will listen for keyboard inputs to control the robot arm.

#### Running Path Following Script manually

As always you have to ssh into the raspberry pi as described above. Afterwards navigade to the '~/Desktop/sunny-robot-arm/src/arm.py' file and in the __if __name__ == "__main__":__ section, you can change the code to what ever you want to run. Currently there should be script that runs finnish path but it may been mofidied to something else:)

Once you hacve modified the code, you can run the script by typing:

```bash
cd ~/Desktop/sunny-robot-arm
python src/arm.py
```

This will execute the script and the robot arm will start following the path defined in the script.

## Using the Web Interface

### Basics

In the web ui, you will see following buttons:

- **Init Arm**: This button initializes the robot arm, setting it to a default position.
- **Play Path**: This button will first initialize motors and then display the page from 
which you can select the path to follow, duration and the behavior of the lamp. 
- **Manual Control**: This button will open a new page where you can control the robot arm manually. Lower will be image describing the buttons that are found on this page.
- **Sensor Test**: This button will start the test that will allow you to check that they are working and correctly calibrated. After clicking button there are comprehensive instructions on how to complete the test.
- **Shutdown**: This button will move arm in such position where power can be safely turned off without damaging the arm.

### Manual Control Page

On this page you can control motors via six different buttons, which will turn arm in different directions which are described in the image below. You can control arm by single clicks or by holding the button down. 

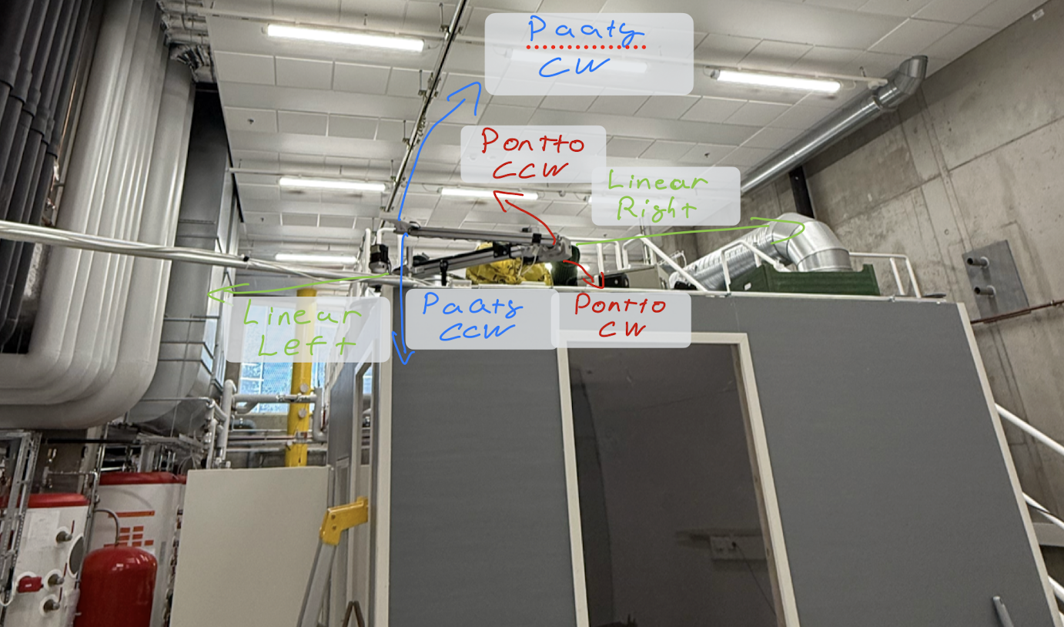
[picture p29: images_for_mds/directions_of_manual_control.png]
Manual Control Directions


On the bottom of the page you can also set up how much each click will turn motor. This is done by increasing "step size" value.
One step size transfers to 1 degree in rotation joints (pontto / paaty) and 1 cm in linear joint (linear rail).

Also if direction image is not clear enough, you can figure out directions of the arm by setting the step size to 1, and clicking the buttons one by one. This will move the arm slowly and you can see how it moves in real time.

If in any point you can interrupt the manual control by clicking the "Stop" button. This will stop all motors immediately and redirect you to the main page. After this you can continue using the web interface as usual.

### Path Following Page

Page offers in total four different paths to follow:

- **Test path**: Is just basic path of two points, in which arm moves from point A to point B and set up the lamp to blue in the point A and to green in point B.
- **Finnish path**: Is a path that follows path of finnish path on 21st of June 2025. In total path has 99 points that are calculated with 10min intervals. So you want to exact follow of the path, durations should be set to 59400 (as 99 * 10min = 990min = 59400s).
- **Singapore path v1** and **Singapore path v2**: These are two paths of the singaporian sun, on the same day as in the finnish path. The difference between paths in relias in how unreachable points were handeled while creating paths. This differences are described in tha math notebook which can be found in 'documentation/math.md' file. Both paths ahve 69 points that are calculated with 10min intervals. So you want to exact follow of the path, durations should be set to 41400 (as 69 * 10min = 690min = 41400s).
- **Duration**: Is selector of how long the path will take to follow. Timer will start then robot has reached the first point of the path. Notice that robot doesn't take into account the time it takes to move from point to point, so if durations is set to low, robot will go though path as fast as possible, but it will not finnish the path in time
- **Lamp**: This is check box that allows you to set the lamp to change color in each point of the path. If checked, lamp will change color based on the estimations of the sun's color in that point. If not checked, arm will not change color of the lamp, in other occasion then when it has to warn surroundings of the arm's movement. After warning isn't needed anymore, lamp will restore to the color it was set to before warning.

## Controlling the lamp

The lamp is powered by wled, which is a software that allows you to control the lamp via web interface. You can access the wled interface by navigating to `http://...` in your web browser while connected to the lab network.

For more instructions on how to use the wled interface, please refer to the [wled documentation](https://kno.wled.ge)

## API

While the web server is running, you can access the REST API endpoints for programmatic control. All endpoints return JSON responses with status information.

### Base URL
```
http://...:5000
```

### Stoping the Robot
To stop the robot at any points, just call the index endpoint `/`:
```bash
curl "http://...:5000/"
``` 
or 
```bash
curl "http://...:5000/stop_arm"
```

### Main Control Endpoint: `/move_arm`

All robot control commands use the `/move_arm` endpoint with different `cmd` parameters:

#### Manual Control Commands

**Step-based Movement (for manual jogging):**
```bash
# Move joints by step increments
curl "http://...:5000/move_arm?cmd=motor_paaty_up"      # Pitch up
curl "http://...:5000/move_arm?cmd=motor_paaty_down"    # Pitch down  
curl "http://...:5000/move_arm?cmd=motor_pontto_ccw"    # Rotate counter-clockwise
curl "http://...:5000/move_arm?cmd=motor_pontto_cw"     # Rotate clockwise
curl "http://...:5000/move_arm?cmd=motor_rail_right"    # Rail right
curl "http://...:5000/move_arm?cmd=motor_rail_left"     # Rail left

# Adjust step size
curl "http://...:5000/move_arm?cmd=pl"                 # Increase step size (+10)
curl "http://...:5000/move_arm?cmd=mn"                 # Decrease step size (-10)
curl "http://...:5000/move_arm?cmd=set_step_size&to=5" # Set specific step size
```

Directions in which the arm will move are described in "Manual Control Page" section above.

#### Precise Motor Control

**Move by relative angle/distance:**
```bash
# Move motor by specified amount (with safety checking)
curl "http://...:5000/move_arm?cmd=by_angle&motor=pontto&angle=45&speed=0.3&check_safety=1"
curl "http://...:5000/move_arm?cmd=by_angle&motor=paaty&angle=-30&speed=0.5&check_safety=0"
curl "http://...:5000/move_arm?cmd=by_distance&dist=100&speed=0.2&check_safety=1"
```

**Move to absolute angle/distance:**
```bash
# Move motor to absolute position
curl "http://...:5000/move_arm?cmd=to_angle&motor=pontto&angle=90&speed=0.4&check_safety=1"
curl "http://...:5000/move_arm?cmd=to_angle&motor=paaty&angle=45&speed=0.3&check_safety=0"
curl "http://...:5000/move_arm?cmd=to_distance&dist=200&speed=0.5&check_safety=1"
```

#### Coordinate-based Movement

**Move to 3D point:**
```bash
# Move end-effector to specific coordinates (x, y, z in mm)
curl "http://...:5000/move_arm?cmd=to_point&x=500&y=300&z=800&speed_joints=0.2&speed_rail=0.4&check_safety=1"
```

**Move to joint configuration:**
```bash
# Move to specific joint angles and rail position
curl "http://...:5000/move_arm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"
```

#### System Commands

**Initialize robot:**
```bash
curl "http://...:5000/move_arm?cmd=init"
```

### Parameters

| Parameter | Type | Description | Default |
|---|---|---|---|
| `cmd` | string | Command type (required) | - |
| `motor` | string | Motor name: `pontto`, `paaty` | - |
| `angle` | float | Angle in degrees | - |
| `dist` | float | Distance in mm | - |
| `x`, `y`, `z` | float | World frame 3D coordinates in mm | - |
| `theta_1`, `theta_2`, `delta_r` | float | Joint angles (°) and rail position (mm) | - |
| `speed` | float | Movement speed (0.0-1.0) | varies |
| `speed_joints` | float | Joint movement speed (0.0-1.0) | 0.1 |
| `speed_rail` | float | Rail movement speed (0.0-1.0) | 0.5 |
| `check_safety` | int | Enable safety checking (0/1) | 1 |
| `to` | int | Target value for step size | - |

### Response Format

All endpoints return JSON with the following structure:
```json
{
  "status": "ok",           // "ok" or "error"
  "message": "Operation completed successfully", // Usually specifing the starting and ending positions
  "step_size": 10          // Current step size (when applicable)
}
```

### Error Responses

```json
{
  "status": "error",
  "message": "Inverse kinematics failed: Target position unreachable", // Error message with details
  "step_size": 10        // Current step size (when applicable)
}
```

### Safety Features

- **Collision Detection**: When `check_safety=1`, the system verifies movements won't cause collisions, but this assumes that the robot has been properly homed before the use and no errors have occurred.
- **Joint Limits**: Automatic enforcement of joint angle and rail position limits  
- **Kinematics Validation**: Ensures target positions are reachable before movement
- **Multi-motor Coordination**: Prevents unsafe movements that would require coordinated motion

### Example Python Usage

```python
import requests

# Move to specific point with safety checking
response = requests.get("http://localhost:5000/move_arm", params={
    'cmd': 'to_point',
    'x': 600,
    'y': 400, 
    'z': 700,
    'speed_joints': 0.2,
    'speed_rail': 0.4,
    'check_safety': 1
})

result = response.json()
if result['status'] == 'ok':
    print(f"Success: {result['message']}")
else:
    print(f"Error: {result['message']}")
```

### Path Execution Endpoint

**Execute complete path sequence:**

```bash
# Execute a saved path with motor initialization and synchronous completion
curl "http://...:5000/api_play_path?name=finish_sun_path.json&duration=3600&lamp=1"
```

| Parameter | Type | Description | Required |
|---|---|---|---|
| `name` | string | Path filename in `/paths` directory | Yes |
| `duration` | int | Total execution time in seconds | Yes |
| `lamp` | int | Enable dynamic lamp colors (0/1) | No (default: 1) |

**Response Format:**

```json
{
  "status": "ok",                                    // "ok" or "error"
  "message": "arm reached the end of the path"       // Completion status
}
```

**Error Responses:**

```json
{
  "status": "error",
  "message": "robot stopped due to safety reasons"   // Error code 69
}
```

```json
{
  "status": "error", 
  "message": "robot stopped due to unknown reasons"  // Other exit codes
}
```

### 📊 Monitoring end points

- `/points`: Get all points of the robot arm
- `/angles`: Get current joint angles
- `/path_points`: Get current path points for visualization
- `/cooling_info`: Get current cooling system status (temperature, fan state)

## Updating code

If some code needs to be updated, you can do it by following these steps:

1. Update the code locally in this repository and push the changes to the remote repository.
2. SSH into the Raspberry Pi as described in the "Getting Started / Troubleshooting" section.
3. Navigate to the sunny-robot-arm directory:
   ```bash
   cd ~/Desktop/sunny-robot-arm
   ```
4. Pull the latest changes from the remote repository:
   ```bash
   git pull
   ```
5. Restart server to apply the changes:
```bash
pkill -f python
python -m ui.main
```

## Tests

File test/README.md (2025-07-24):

# Test Suite for Sunny Robot Arm

This directory contains comprehensive unit tests and integration tests for the Sunny Robot Arm project.

## Test Files

### `test_kinematics_and_safety.py`
Comprehensive unit tests for the kinematics and safety module including:

- **Forward Kinematics Tests**
  - Home position calculations
  - Known configurations
  - Extreme positions
  - Consistency checks

- **Inverse Kinematics Tests**
  - Reachable point solving
  - Unreachable point handling
  - Multiple solution detection
  - Rail limit enforcement
  - Safety integration

- **Solution Selection Tests**
  - Closest solution selection
  - Edge cases handling

- **Safety & Collision Detection Tests**
  - Safe position verification
  - Unsafe position detection
  - Edge-box intersection testing
  - Safety box validation

- **Round-trip Consistency Tests**
  - Forward→Inverse→Forward consistency
  - Error tolerance validation

- **Performance Tests**
  - Execution time validation
  - Batch processing efficiency

### `test_integration_kinematics.py`
Integration tests for realistic scenarios:

- **Robot Initialization**
  - Home position reachability
  - Workspace validation

- **Solar Tracking Simulation**
  - Typical sun positions
  - Workspace coverage

- **Trajectory Following**
  - Smooth path execution
  - Joint movement validation

- **Workspace Boundaries**
  - Limit testing
  - Edge case handling

- **Safety System Integration**
  - End-to-end safety validation

- **Performance Integration**
  - Batch processing
  - Real-time capability

### `test_sun_helper.py`
Unit tests for sun path serialization utilities:

- **TestJsonifyPath**
  - Path-only JSON serialization
  - Path with colors serialization
  - Array structure validation
  - Output format verification

- **TestUnJsonifyPath**
  - JSON file deserialization
  - Data validation and type checking
  - Error handling for invalid files
  - Color data restoration

- **TestPathSerialization**
  - Round-trip serialization consistency
  - Data integrity verification
  - Precision preservation

- **TestEdgeCases**
  - Empty path handling
  - Invalid input validation
  - File operation error cases
  - Malformed JSON handling

### `test_spinning_joints.py`
Comprehensive unit tests for the SpinningJoints stepper motor class:

- **TestSpinningJointsInitialization**
  - Parameter validation and object creation
  - GPIO pin configuration validation
  - Motor specifications (steps/rev, gear ratio, delays)

- **TestStepCalculations**
  - Step timing calculations based on speed percentage
  - Motor stepping logic with direction control
  - GPIO pulse generation and state updates

- **TestAngleMovement**
  - Relative angle movement (move_by_angle)
  - Absolute angle positioning (move_to_angle)
  - Angle limit enforcement and validation

- **TestMotorInitialization**
  - Motor-specific initialization sequences (pontto vs paaty)
  - Limit switch detection and homing routines
  - Initialization timeout and error handling

- **TestSafetyValidation**
  - Angle limit checking and enforcement
  - Error handling for invalid parameters
  - Safety constraint validation

- **TestSharedStateManagement**
  - Multiprocessing shared state coordination
  - Motor-specific shared variable updates (theta_1, theta_2)
  - Cross-process state synchronization

- **TestCleanupAndUtilities**
  - GPIO resource cleanup and management
  - Utility functions (get_steps, get_angle, reset_position)
  - Proper resource deallocation

### `test_linear_rail.py`
Comprehensive unit tests for the LinearRail stepper motor class:

- **TestLinearRailInitialization**
  - Parameter validation for linear stage setup
  - GPIO configuration and mechanical parameters
  - Screw drive pitch and gear ratio validation

- **TestDistanceCalculations**
  - Distance-to-steps conversion calculations
  - Step timing based on speed percentage
  - GPIO control for linear movement

- **TestDistanceMovement**
  - Relative distance movement (move_by_distance)
  - Absolute distance positioning (move_to_distance)
  - Movement direction and step calculation

- **TestMotorInitialization**
  - Limit switch-based homing sequences
  - Back-off positioning after limit detection
  - Multi-direction initialization support

- **TestLimitSwitchHandling**
  - Limit switch detection and response
  - Movement blocking when limits are active
  - Override capabilities with ignore_limit flag

- **TestSharedStateManagement**
  - Shared delta_r state coordination
  - Real-time position tracking across processes
  - State synchronization for multi-process control

- **TestCleanupAndUtilities**
  - Linear stage resource management
  - Position reset and calibration functions
  - Proper GPIO cleanup procedures

### `test_api.py`
Simple API testing script for manual verification:

- Live API endpoint testing
- HTTP request/response validation
- Manual command execution
- Basic integration verification

### `run_tests.py`
Enhanced test runner with multiple execution options:

- Individual test module execution
- Combined test suite running
- Verbose output options
- Specific test class/method targeting

## Running Tests

### Option 1: Using test runner (Recommended)

```bash
python test/run_tests.py                              # Run kinematics unit tests
python test/run_tests.py --verbose                    # Verbose output  
python test/run_tests.py --integration               # Run integration tests
python test/run_tests.py --sun-helper                # Run sun_helper utility tests
python test/run_tests.py --hardware                  # Run all hardware component tests
python test/run_tests.py --spinning-joints           # Run spinning joints motor tests
python test/run_tests.py --linear-rail               # Run linear rail motor tests
python test/run_tests.py --all                       # Run all test modules
python test/run_tests.py --specific TestForwardKinematics  # Run specific test class
python test/run_tests.py --method test_forward_kinematics_home_position  # Run specific test method
```

### Option 2: Using pytest

```bash
# From project root directory
python -m pytest test/ -v

# Run specific test file
python -m pytest test/test_kinematics_and_safety.py -v
python -m pytest test/test_sun_helper.py -v
python -m pytest test/test_move_arm_api.py -v

# Run specific test class
python -m pytest test/test_kinematics_and_safety.py::TestForwardKinematics -v

# Run with coverage
python -m pytest test/ --cov=src --cov-report=html
```

### Option 3: Direct execution

```bash
# From project root directory
cd test
python test_kinematics_and_safety.py
python test_integration_kinematics.py
python test_sun_helper.py
python test_move_arm_api.py
```

### Option 4: Manual API testing

```bash
# Start the Flask server first
python -m ui.main

# Then run API tests in another terminal
python test/test_api.py
```

## Test Dependencies

Make sure you have all required packages installed:

```bash
pip install numpy scipy matplotlib pvlib pandas pytest pytest-cov flask requests
```

For API testing specifically:

```bash
# Core testing packages
pip install unittest-mock

# For integration testing  
pip install tempfile json
```

## Test Categories

### Unit Tests
- Individual function testing
- Input validation
- Error handling
- Edge cases
- Performance benchmarks

### Integration Tests  
- Multi-component workflows
- Realistic scenarios
- System-level validation
- Performance under load

## Expected Test Results

### Passing Tests
Most tests should pass when run on properly configured hardware. Some tests may be skipped if:
- Positions are outside robot workspace
- Safety constraints prevent certain movements
- Hardware-specific configurations differ

### Performance Benchmarks
- Inverse kinematics: >50 solutions/second
- Forward kinematics: >1000 calculations/second  
- Safety checking: >100 checks/second
- Position accuracy: <1mm error tolerance

## Debugging Failed Tests

### Import Errors
```bash
# Make sure you're in the project root
pwd  # Should show .../sunny-robot-arm

# Check Python path
python -c "import sys; print(sys.path)"

# Install missing dependencies
pip install -r requirements.txt
```

### Calculation Errors
- Check that config.py values match your hardware
- Verify safety box definitions are appropriate
- Ensure coordinate frames are correctly defined

### Performance Issues
- Run tests on dedicated hardware without GUI interference
- Check for CPU throttling or high system load
- Verify NumPy is using optimized BLAS libraries

## Adding New Tests

### Test Structure
```python
class TestNewFeature(unittest.TestCase):
    def setUp(self):
        """Set up test fixtures before each test method."""
        pass
    
    def test_specific_behavior(self):
        """Test description."""
        # Arrange
        input_data = ...
        
        # Act  
        result = function_under_test(input_data)
        
        # Assert
        self.assertEqual(result, expected)
    
    def tearDown(self):
        """Clean up after each test method."""
        pass
```

### Best Practices
- Use descriptive test names
- Test both success and failure cases
- Include performance tests for critical functions
- Use subTest() for multiple related test cases
- Mock hardware dependencies when testing logic
- Validate numerical accuracy with appropriate tolerances

## Coverage Goals

Target test coverage:

- **Kinematics functions**: >95%
- **Safety functions**: >90%  
- **Utility functions**: >80%
- **Error handling**: >95%
- **API endpoints**: >85%
- **Path serialization**: >95%

Run coverage analysis:

```bash
python -m pytest test/ --cov=src --cov-report=term-missing
```

This will show exactly which lines need additional test coverage.

## Current Test Status

### Fully Tested Modules

- ✅ **sun_helper.py**: 18 tests covering all path serialization functions
- ✅ **kinematics_and_safety.py**: Comprehensive coverage of all kinematics functions
- ✅ **spinning_joints.py**: 22 tests covering stepper motor control for rotating joints
- ✅ **linear_rail.py**: 22 tests covering linear stepper motor stage control
- ✅ **Flask API structure**: All endpoints have been manually tested
- ✅ **Flask API functionality**: Fully tested manually with various scenarios

### Partially Tested Modules  

- 🟡 **Integration workflows**: Basic coverage, expanding for real-world scenarios

### Test Metrics

- **Total test files**: 6
- **Total test classes**: 20+
- **Total test cases**: 100+
- **Estimated coverage**: >90% for core modules

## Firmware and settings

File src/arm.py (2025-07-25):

"""
arm.py
~~~~~~

High-level Arm controller that coordinates two rotary joints (pontto, paaty),
one linear rail, a dynamic lamp, and a warning sound during path playback.

Key Responsibilities:
  - Initialize and shutdown hardware axes and lamp/sound
  - Load and manage execution of 3D paths with safety checks
  - Step joints/rail in small increments to follow the path
  - Coordinate lamp effects and warning buzzer on large moves or errors

Dependencies:
  - SpinningJoints, LinearRail for motor control
  - Lamp, WarningSound for visual/audio alerts
  - Kinematics (inverse_kinematics, forward_kinematics, choose_solution)
  - Shared multiprocessing.Namespace for cross-process state
"""
import time
import numpy as np
import matplotlib.pyplot as plt
from mpl_toolkits.mplot3d import Axes3D
from matplotlib.animation import FuncAnimation
import os
from dotenv import load_dotenv
load_dotenv() 

from kinematics_and_safety import *
from sun_helper import *
from lamp import Lamp
from linear_rail import LinearRail
from spinning_joints import SpinningJoints
from config import *
from warning_sound import WarningSound

class Arm:
    """
    Controller for a 3-DOF robot arm:
      - Motor #1: pontto (rotates horizontally)
      - Motor #2: paaty  (rotates vertically)
      - Motor #3: linear rail (slides in Y)
    Also controls a lamp and warning buzzer during motion.
    """

    def __init__(self,
                 shared,
                 init_pos: np.ndarray = [BASE_X_OFFSET, BASE_Y_OFFSET, BASE_Z_OFFSET],
                 dz1: float = PONTTO_Z_OFFSET,
                 dx1: float = PONTTO_X_OFFSET,
                 dx2: float = PAATY_X_OFFSET,
                 dy1: float = PONTTO_ARM_LENGTH,
                 end_link_length: float = PAATY_ARM_LENGTH,
                 theta_r: float = RAIL_ANGLE,
                 rail_length: float = RAIL_MAX_LIMIT,
                 lamp_url: str = os.getenv("WLED_ADR")
                 ) -> None:
        """
        Initialize motor drivers, lamp, and warning sound.

        :param shared: multiprocessing.Namespace for sharing joint states
        :param init_pos: translation matrix to the pos of the base
        :param dz1, dx1, dx2, dy1: offsets of the robots joints
        :param end_link_length: length of the second arm of the robot
        :param theta_1: angle of the rail
        :param: rail_length: length of the rail
        :param lamp_url: HTTP URL for controlling the RGB lamp
        """
        self.init_pos=init_pos
        self.dz1=dz1
        self.dx1=dx1
        self.dx2=dx2
        self.dy1=dy1
        self.end_link_length=end_link_length
        self.theta_r=theta_r
        self.rail_length=rail_length

        # basic variables
        self.theta_1 = None
        self.theta_2 = None
        self.delta_r = None
        
        # Path-following state
        self.required_theta_1 = None
        self.required_theta_2 = None
        self.required_delta_r = None
        self.current_path = None
        self.current_path_colors = None
        self.iteration = 0
        self.duration_per_point = 0
        
        self.shared = shared

        self.motor_paaty = SpinningJoints(shared, 
                                          pulse_pin=PAATY_MOTOR_PULSE_PIN, 
                                          dir_pin=PAATY_MOTOR_DIR_PIN, 
                                          limit_pin=PAATY_MOTOR_SENSOR_PIN, 
                                          name="paaty", 
                                          gear_ratio=PAATY_MOTOR_GEAR_RATIO)
        
        self.motor_pontto = SpinningJoints(shared, 
                                           pulse_pin=PONTTO_MOTOR_PULSE_PIN, 
                                           dir_pin=PONTTO_MOTOR_DIR_PIN, 
                                           limit_pin=PONTTO_MOTOR_SENSOR_PIN, 
                                           name="pontto",
                                           gear_ratio=PONTTO_MOTOR_GEAR_RATION)
        
        self.motor_rail = LinearRail(shared, 
                                     pulse_pin=RAIL_MOTOR_PULSE_PIN, 
                                     dir_pin=RAIL_MOTOR_DIR_PIN, 
                                     limit_pin=RAIL_MOTOR_SENSOR_PIN, 
                                     gear_ratio=RAIL_MOTOR_GEAR_RATIO)

        self.lamp = Lamp(https_url=lamp_url)
        # self.warning_sound = WarningSound("sounds/ai_warning_2.wav")


    def init(self) -> bool:
        """
        Home all three axes and reset to known base pose.
        Blink the lamp and sound warning while homing.

        Returns True if successful, else exits with code 67.
        """

        # Indicate homing in progress
        self.lamp.set_to_blink()

        warning_sound = WarningSound("sounds/ai_warning_2.wav")
        warning_sound.start()

        try:
            print("Starting init")

            self.motor_paaty.init_motor(speed=0.1)
            self.motor_pontto.init_motor(speed=0.1)
            self.motor_rail.init_motor(direction=1)

        except TimeoutError:
            print("One of the motor couldn't init")
            exit(67)
            return False
        
        # Assume homed angles/position from config constants
        self.motor_pontto.shared.theta_1 = self.motor_pontto.angle = self.theta_1 = RAIL_ANGLE
        self.motor_paaty.shared.theta_2 = self.motor_paaty.angle = self.theta_2 = THETA_2_VAL_IN_INIT
        self.motor_rail.shared.delta_r = self.motor_rail.distance = self.delta_r = DELTA_R_VAL_IN_INIT

        # Restore lamp to solid off state and stop buzzer
        self.lamp.set_brightness(0)
        self.lamp.set_to_solid()
        warning_sound.stop()

        return True


    def shutdown(self) -> None:
        """
        Park the arm: blink lamp, move all axes back to home, then solid lamp off.
        """

        self.lamp.set_to_blink()
        
        self.motor_paaty.shutdown()
        self.motor_pontto.shutdown()
        self.motor_rail.init_motor()

        self.lamp.set_brightness(0)
        self.lamp.set_to_solid()


    def init_path(self, path: str | np.ndarray, duration: float, dynamic_lamp: bool = True):
        """
        Load a path for playback and set timing.

        :param path: filepath (str) or Nx3 numpy array
        :param duration: total traversal time (sec)
        :param dynamic_lamp: if True, lamp color follows path_colors
        """

        # Load JSON if provided a filename
        if type(path) == str:
            self.current_path, self.current_path_colors = un_jsonify_path(path)
        elif type(path) == np.ndarray or type(path) == np.array:
            self.current_path = path
        else:
            raise ValueError("Path must be filepath or numpy array")
        
        # Disable lamp colors if static desired
        if not dynamic_lamp:
            self.current_path_colors = None
        
        # Compute pause duration per waypoint
        self.duration_per_point = duration / len(self.current_path)
        self.shared.path = self.current_path
        self.iteration = self.shared.path_it = 0


    def move(self, speeds=None, check_safety=True):
        """
        Advance arm by one waypoint in current_path.
        Returns False to signal 'more to do', or exits with codes 68/69 on completion/error.
        """

        if self.current_path is None:
            raise ValueError("Initialize path first")

        # Check end of path
        if self.shared.path_it >= len(self.current_path):
            print("Robot has already reached the end of the path")
            exit(68)
            return
        
        # Set default speeds if not provided
        if speeds is None:
            speed_joint = 0.1
            speed_rail = 0.5
        else:
            speed_joint, speed_rail = speeds

        # Throttle to maintain timing
        since_last_move = time.time() - self.shared.timer
        if since_last_move < self.duration_per_point:
            print(f"Waiting for {self.duration_per_point - since_last_move:.2f} seconds before next move")
            time.sleep(self.duration_per_point - since_last_move)
            # exit(66)
        self.shared.timer = time.time()
        
        try:
            # Compute or reuse next target joint values
            if self._target_not_set():
                distance_to_target = self._compute_next_target(check_safety=check_safety)

            # Alert if large move
            warning_sound = WarningSound("sounds/ai_warning_2.wav")
            original_lamp_state = self.lamp.get_state()
            if distance_to_target > MIN_WARNING_DISTANCE:
                self.lamp.set_to_blink()
                warning_sound.start()
        
            print(f"Moving to target: theta_1={self.required_theta_1}, "
                  f"theta_2={self.required_theta_2}, delta_r={self.required_delta_r}")

            MAX_ITERATIONS = 1000
            iteration = 0

            # Loop stepping each axis until all at target or error
            for _ in range(MAX_ITERATIONS):
                done = True
                # Step pontto joint toward required_theta_1
                if not self._step_towards('theta_1', self.required_theta_1, check_safety):
                    self.motor_pontto.move_to_angle(self.required_theta_1, speed=speed_joint)
                    done = False
                # Step rail
                if not self._step_towards('delta_r', self.required_delta_r, check_safety):
                    self.motor_rail.move_by_distance(self.required_delta_r, speed=speed_rail)
                    done = False
                # Step paaty joint
                if not self._step_towards('theta_2', self.required_theta_2, check_safety):
                    self.motor_paaty.move_to_angle(self.required_theta_2, speed=speed_joint)
                    done = False
                if done:
                    break
            if not done:
                raise RuntimeError("Could not reach target safely")

            # Clear target for next iteration
            self._clear_target()

            # Update lamp color or restore prior state
            if self.current_path_colors is not None:
                color = self.current_path_colors[self.shared.path_it]
                # self.lamp.set_color(*color, verbal=True)
                self.lamp.set_to_solid(*color)
            else:
                self.lamp.set_state(original_lamp_state)
                # self.lamp.set_to_solid()
            warning_sound.stop()

            # on first iteration timer starts only after robot has reached the point
            if self.shared.path_it == 0:
                self.shared.timer = time.time()

            # Advance to next waypoint and signal caller
            self.shared.path_it += 1
            return False
        except ValueError as e:
            print(f"Error: {e}")
            print("Stopping robot.")
            exit(69)

    # --- Internal helpers ---

    def _target_not_set(self) -> bool:
        '''Checks if target is set'''
        return any(v is None for v in (self.required_theta_1, self.required_theta_2, self.required_delta_r))


    def _step_towards(self, attr: str, target: float, step_size: int = 1, check_safety: bool = True) -> None:
        """
        Returns True if 'attr' (theta_1, theta_2, or delta_r) is already at target.
        Raises ValueError if any intermediate step would violate safety.
        """
        current = getattr(self.shared, attr)
        diff = target - current

        print("diff in step", diff)

        if abs(diff) < 0.226:  # Already at target (with tolerance)
            return True

        direction = diff / abs(diff)  # +1 or -1
        steps = int(abs(diff) // step_size)
        remainder = abs(diff) % step_size

        # Simulate hypothetical steps and check safety
        for i in range(steps):
            intermediate = current + direction * step_size * (i + 1)
            if check_safety:
                self._check_if_hypothetical_safe(attr, intermediate)

        # Check the remainder step (final position)
        if remainder > 0:
            final = current + direction * (steps * step_size + remainder)
            if check_safety:
                self._check_if_hypothetical_safe(attr, final)

        # If all steps are safe, perform the final move
        setattr(self, attr, target)
        print(f"Moved {attr} to {target} safely.")
        return False


    def _check_if_hypothetical_safe(self, attr: str, value: float) -> bool:
        """
        Checks whether setting shared.attr to value keeps the arm collision-free.
        Raises ValueError if unsafe.
        """
        # Temporarily set value
        current_state = {
            'theta_1': self.shared.theta_1,
            'theta_2': self.shared.theta_2,
            'delta_r': self.shared.delta_r,
        }

        current_state[attr] = value

        if not check_solutions_safety(
            (current_state['theta_1'], current_state['theta_2'], current_state['delta_r'])
        ):
            raise ValueError(
                f"Unsafe configuration detected when moving {attr} to {value}."
            )


    def _quantize(self, desired: float, current: float, motor) -> float:
        """Snap a desired angle/distance to nearest actual motor step."""
        step_angle = 360.0 / (motor.step_per_rev * motor.gear_ratio)
        # how many steps from current → desired
        n_steps = int((desired - current) / step_angle)
        return current + n_steps * step_angle


    def _compute_next_target(self, check_safety: bool = True) -> float:
        """
        Inverse-kinematics to compute required angles/distance for next waypoint.
        Quantizes them to nearest motor step increments.
        Returns Euclidean distance from current end-effector to next waypoint.
        """
        next_point = self.current_path[self.shared.path_it]
        curr_point = forward_kinematics(self.shared.theta_1, self.shared.theta_2, self.shared.delta_r)[-1]

        sols = inverse_kinematics(*next_point, verbal=False, check_safety=check_safety)
        self.required_theta_1, self.required_theta_2, self.required_delta_r = choose_solution(
            sols, (self.shared.theta_1, self.shared.theta_2, self.shared.delta_r)
        )

        # Snap to full motor steps
        self.required_theta_1 = self._quantize(self.required_theta_1, self.shared.theta_1, self.motor_pontto)
        self.required_theta_2 = self._quantize(self.required_theta_2, self.shared.theta_2, self.motor_paaty)
        self.required_delta_r = self._quantize(self.required_delta_r, self.shared.delta_r, self.motor_rail)

        print(f"Next target: theta_1={self.required_theta_1}, "
                f"theta_2={self.required_theta_2}, delta_r={self.required_delta_r}")

        # returns distance to next point
        return np.linalg.norm(np.array(next_point) - np.array(curr_point))


    def _clear_target(self) -> None:
        """Reset required_theta_1/2 and required_delta_r to None."""
        self.required_theta_1 = None
        self.required_theta_2 = None
        self.required_delta_r = None


    def draw_all(self, index, ax) -> None:
        '''Helper function for drawing all stuff, used in testing'''
        ax.clear()
        try:
            self.move()
        except ValueError as e:
            print(f"Error during move: {e}")
        draw_all_safety_boxes(ax)
        draw_robot(ax, points=forward_kinematics(self.theta_1, self.theta_2, self.delta_r))
        plot_path(ax, self.current_path, linestyle='None')


# Example usage
if __name__ == "__main__":

    from multiprocessing import Process, Queue, Manager
    manager = Manager()
    shared = manager.Namespace()
    shared.theta_1 = 0
    shared.theta_2 = 0
    shared.delta_r = 0
    shared.timer = 0
    shared.path_it = 0


    arm = Arm(shared)
    arm.init()
    arm.init_path(path_file_path="paths/finish_sun_path.json", duration=0)

    while True:
       arm.move(shared=shared)
       time.sleep(0.1)

    # fig = plt.figure(figsize=(9, 6))
    # ax = fig.add_subplot(111, projection='3d')
# 
    # ani = FuncAnimation(fig, arm.draw_all, frames=len(arm.current_path), fargs=(ax,), interval=100)
    # plt.show()

    

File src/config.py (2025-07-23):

PONTTO_Z_OFFSET = 210
PONTTO_X_OFFSET = 57.5
PONTTO_ARM_LENGTH = 835
PONTTO_MOTOR_MIN_ANGLE = -172

PAATY_X_OFFSET = 105
PAATY_ARM_LENGTH = 905

BASE_X_OFFSET = 920
BASE_Y_OFFSET = -240
BASE_Z_OFFSET = 0

BASE_TRANSFORM_MATRIX = [[1, 0, 0, BASE_X_OFFSET], 
                         [0, 1, 0, BASE_Y_OFFSET], 
                         [0, 0, 1, BASE_Z_OFFSET], 
                         [0, 0, 0, 1]]

RAIL_ANGLE = 137.6

THETA_2_VAL_IN_INIT = 90 + 73.17
DELTA_R_VAL_IN_INIT = 0.0

RAIL_MIN_LIMIT = -0.1   # This is basically zero, but to allow -0 value to pass it's nto actually zero
RAIL_MAX_LIMIT = 731.3
SCREW_DRIVE_PITCH = 10.0

PONTTO_MOTOR_PULSE_PIN = 13
PONTTO_MOTOR_DIR_PIN = 26
PONTTO_MOTOR_SENSOR_PIN = 22
PONTTO_MOTOR_GEAR_RATION = 5*32/10

PAATY_MOTOR_PULSE_PIN = 20
PAATY_MOTOR_DIR_PIN = 19
PAATY_MOTOR_SENSOR_PIN = 23
PAATY_MOTOR_GEAR_RATIO = 5

RAIL_MOTOR_PULSE_PIN = 27
RAIL_MOTOR_DIR_PIN = 4
RAIL_MOTOR_SENSOR_PIN = 24
RAIL_MOTOR_GEAR_RATIO = 1

MOTORS_MIN_DELAY = 1e-4
MOTORS_MAX_DELAY= 1e-3

FAN_PIN = 18
MIN_TEMP_IN_BOX = 30.0
MAX_TEMP_IN_BOX = 60.0

SAFE_ZONE_Y_CORD = 1200
SAFE_ZONE_X_CORD = -1100

MIN_WARNING_DISTANCE = 100

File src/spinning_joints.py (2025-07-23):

from gpiozero import DigitalOutputDevice
import time
from gpiozero import Button
from signal import pause

from config import *

from multiprocessing import Event

class SpinningJoints:
    def __init__(self, 
                 shared, 
                 pulse_pin, 
                 dir_pin, 
                 name, 
                 limit_pin, 
                 step_per_rev=1600, 
                 gear_ratio=5, 
                 min_delay: float = MOTORS_MIN_DELAY, 
                 max_delay: float = MOTORS_MAX_DELAY, 
                 angle_limit=360):
        """
        Initialize the stepper motor with the given GPIO pins.

        :param pulse_pin: GPIO pin for sending step pulses.
        :param dir_pin: GPIO pin for setting the direction.
        """
        # asserts:)
        assert isinstance(pulse_pin, int), "Pulse pin must be an integer."
        assert isinstance(dir_pin, int), "Direction pin must be an integer."
        assert isinstance(name, str), "Name must be a string"
        assert isinstance(step_per_rev, int), "Steps per revolution must be an integer."
        assert isinstance(gear_ratio, (int, float)), "Gear ratio must be a number."
        assert isinstance(min_delay, (int, float)), "Minimum delay must be a number."
        assert isinstance(max_delay, (int, float)), "Maximum delay must be a number."
        assert min_delay >= 0, "Minimum delay must be non-negative."
        assert max_delay >= min_delay, "Maximum delay must be greater than or equal to minimum delay."

        self.shared = shared

        self.name = name
        
        self.pulse = DigitalOutputDevice(pulse_pin)
        self.direction = DigitalOutputDevice(dir_pin)

        self.limit_event = Event()

        self.limit_switch = Button(limit_pin, pull_up=True, bounce_time=0.0001)
        self.limit_switch.when_pressed = lambda: (print(f"Metal detected by {self.name}"), 
                                                self.limit_event.set())
        self.limit_switch.when_released = lambda: (print(f"No metal anymore by {self.name}"), 
                                                    self.limit_event.clear())

        self.angle_limit = angle_limit

        self.angle = 0
            
        self.steps = 0
        self.step_per_rev = step_per_rev
        self.min_delay = min_delay
        self.max_delay = max_delay
        self.gear_ratio = gear_ratio


    def calc_delay(self, speed_percent):
        if not (0 <= speed_percent <= 1):
            raise ValueError("Speed percent must be between 0 and 1.")
        return self.min_delay + (self.max_delay - self.min_delay) * (1 - speed_percent)
    
    def init_motor(self, speed=0.1):
        # pontto motor init is little bit more complicated to not get the 
        # cabel tangled there for it has own init sequence
        if self.name=="pontto":
            direction_change = False

            direction = 1

            while not self.limit_event.is_set():
                if not direction_change and abs(self.angle) > (180-RAIL_ANGLE):
                    self.angle = 0
                    time.sleep(2)
                    direction = -1 * direction
                    direction_change = True

                if direction_change and abs(self.angle) > (180 + RAIL_ANGLE):
                    raise TimeoutError("Motor didn't find init pos")

                self.step(direction=direction, speed=speed)

            if not direction_change:
                self.move_by_angle(-10, speed=speed)
                time.sleep(2)
                while not self.limit_event.is_set():
                    self.step(direction=-1, speed=speed)
            else:
                time.sleep(2)
                self.move_by_angle(-1, speed=speed)

        else:
            # first it gets out of the shutdown pos by spinning 15 degrees
            self.move_by_angle(-17, speed=speed)
            time.sleep(1)

            # then spins until it finds the limit switch
            while not self.limit_event.is_set():
                if abs(self.angle) > 270:
                    raise TimeoutError("Motor didn't find init pos")
                self.step(direction=-1, speed=speed)

        self.reset_position()
        print(f"Motor {self.name} initialized")

    def shutdown(self):
        if self.name == "pontto":
            self.init_motor()

        if self.name == "paaty":
            self.init_motor()
            time.sleep(2)
            self.move_by_angle(10.5, speed=0.01)

    def step(self, direction=1, speed=0.1):
        if abs(direction * (360 / (self.step_per_rev * self.gear_ratio)) > self.angle_limit):
            raise ValueError("Angle exceeded the limit.")
        
        if direction not in [-1, 1]:
            raise ValueError("Direction must be 1 (forward) or -1 (backward).")

        self.direction.value = 1 if direction == 1 else 0
        delay = self.calc_delay(speed)

        self.pulse.on()
        time.sleep(delay)
        self.pulse.off()
        time.sleep(delay)
        self.steps -= direction
        self.angle -= direction * (360 / (self.step_per_rev * self.gear_ratio))
        # self.angle = round(self.angle, 3)

        if self.name=="pontto":
            self.shared.theta_1 -= direction * (360 / (self.step_per_rev * self.gear_ratio))
            # self.shared.theta_1 = round(self.shared.theta_1, 3)
        elif self.name=="paaty":
            self.shared.theta_2 -= direction * (360 / (self.step_per_rev * self.gear_ratio))
            # self.shared.theta_2 = round(self.shared.theta_2, 3)

    def move_by_angle(self, angle, speed=0.1): #, shared=None):

        # if self.name == "pontto":
        #     self.angle = self.shared.theta_1
        # elif self.name == "paaty":
        #     self.angle = self.shared.theta_2

        if abs(angle) > self.angle_limit:
           raise ValueError("Angle must be between -360 and 360 degrees.")

        print("angle ", self.angle)
        angle_per_step = 360 / (self.step_per_rev * self.gear_ratio)
        steps = int(angle / angle_per_step)
        print("steps ", steps)
        direction = 1 if angle < 0 else -1

        for _ in range(abs(steps)):
            # print("curr ", self.angle)
            self.step(direction=direction, speed=speed)

        # if shared is not None:
        #     if self.name == "pontto":
        #         shared.theta_1 = self.angle
        #     elif self.name == "paaty":
        #         shared.theta_2 = self.angle

    def move_to_angle(self, target_angle, speed=0.1): #, shared=None):
        if abs(target_angle) > self.angle_limit:
            raise ValueError("Target angle must be between -360 and 360 degrees.")

        if self.name == "pontto":
            self.angle = self.shared.theta_1
        elif self.name == "paaty":
            self.angle = self.shared.theta_2

        angle_diff = target_angle - self.angle
        print("diff", angle_diff)

        self.move_by_angle(angle_diff, speed=speed) #, shared=shared)
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

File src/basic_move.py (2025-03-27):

from time import sleep
import threading
from gpiozero import DigitalOutputDevice
from cooling import FanController

# GPIO pin assignments
direction_pins = [26, 4, 19]  # brown wires
pulse_pins     = [13, 27, 20] # white wires

cw_direction  = False
ccw_direction = True

# Setup gpiozero devices
direction_outputs = [DigitalOutputDevice(pin) for pin in direction_pins]
pulse_outputs     = [DigitalOutputDevice(pin) for pin in pulse_pins]

# Set initial direction (clockwise)
for direction in direction_outputs:
    direction.value = cw_direction

# Start the fan controller in a separate thread
cooler = FanController()
fan_thread = threading.Thread(target=cooler.run, daemon=True)
fan_thread.start()

try:
    while True:
        for _ in range(1600):
            for pulse in pulse_outputs:
                pulse.on()
            sleep(1e-5)
            for pulse in pulse_outputs:
                pulse.off()
            sleep(1e-5)

except KeyboardInterrupt:
    print("Interrupted. Cleaning up.")
    for pin in direction_outputs + pulse_outputs:
        pin.close()

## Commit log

2025-02-03 test code for cylinder
2025-02-03 first code for arm
2025-02-03 script for generation all world stuff Now has the box, slider, cylinder as robots base and path
2025-02-03 added first arm
2025-02-10 made working path tracer
2025-02-17 started arm class
2025-02-17 added comments and corrected mistakes
    [arm.py]
2025-02-17 added tests for arm
2025-02-17 added joints class and added overwrite of ==
2025-02-17 modified to support joints
2025-03-08 added folder with all motor documents
2025-03-08 basic tutorial for moving motor
2025-03-08 added basic class for motor control and tests for it
2025-03-10 moved tests in different locations and fixed silly mistakes
    [arm.py, motor.py, test_arm.py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]
2025-03-10 removed debugging prints
2025-03-23 script for moving motors with keyboard
2025-03-23 script for controlling motors with command like "move to the angle"
2025-03-24 added motor pins
2025-03-24 added basic files of controlling fan and checking temperature
2025-03-25 script to control fan based on temperature, not tested yet:)
2025-03-25 added creation of automatic fan controller that is put on own thread
2025-03-27 circuit diagram
2025-03-27 started raspi wiring diagram
2025-03-27 added controller to motor connections
2025-03-27 added print overrites
2025-03-31 1. debugged with raspi 2. fixed problem with ssh not starting right away 3. added env file
    [main.py]
2025-03-31 added gear ratios and changed motors pins
2025-03-31 updated to run on raspi, and poll temperature from there
2025-04-01 uncommented motor
2025-04-01 added the script for moving motors back
2025-04-02 now buttons can be spammed
2025-04-16 changed pinns and motor init
2025-04-17 limit switches now work!
2025-04-24 renamed file to be a only for linear rail
2025-04-24 added second file for spinning motor joints
2025-04-24 added spinning joints
2025-05-12 added induction sensor stuff and correct init functions
    [spinning_joints.py]
2025-05-12 added init of motors
2025-05-25 added pitch to the linear rail, so the movement is based on it
2025-05-30 r&d script for tf matrices. Now it has working forward and invert kinematics
2025-06-11 tried adding the rail, but nothing works yet:(
2025-06-12 finally working inverse kinematics with the rail. Probably should also stress test it with random numbers.
2025-06-12 added solo and mega test for helper. They should both work now (cannot now as the inverse function broke)
    [test_helper.py]
2025-06-12 added debug prints and pointed two breaking points
2025-06-17 deleted debug prints
2025-06-17 kinematics should work so no use for this test file
2025-06-18 added error raising if the init isn't found
    [spinning_joints.py]
2025-06-30 modified the make_step function to check if whole movement of the joint is possible so then we can move the motor fully at once
2025-06-30 modified init so that it skips if sensor is already active
    and also added option to chose speed in init
    [spinning_joints.py]
2025-06-30 tested and fixed move to distance and move by distance
    [linear_rail.py]
2025-06-30 added correct motors to init and added actual motor control in the move (it's working but not fully correct)
    [arm.py]
2025-06-30 started debugging wrong direction spinning, on first glance it wokrs
    [arm.py]
2025-06-30 moved all templates to own files, and started work on the sensor test page
2025-07-01 put play and init into template files and added all rest sensor stuff
2025-07-01 created own style file for sensor test
2025-07-01 added rest sensor test pictures
2025-07-01 added rest of sensor test templates, renamed the original test one to the right sensor test
2025-07-02 added separate init for pontto motor
2025-07-02 last fixes to make it work with test path
    [arm.py]
2025-07-02 added gpio pin cleanup
2025-07-02 added direct control of the motors
2025-07-03 fixed sensor test
2025-07-03 made paaty motor init slower
2025-07-03 corrected the motors
2025-07-03 remade interaction with motors, to relay on arm class. Finished the sensor test
2025-07-03 idea how to stop arm if needed during manual control
2025-07-03 added rest of API motor controll stuf <- must be debugged
    added status checking if process is done
2025-07-03 added current distance variable
2025-07-04 init was fucked, so now it fixed
    [linear_rail.py]
2025-07-04 fixed problem with init when multiprocessing
    [linear_rail.py]
2025-07-04 added stop button
2025-07-04 remade the pontto into to spin less and moved sensors into event as well
2025-07-04 sensors moved to events
2025-07-04 started work on fixing the API calls, currently by angle should work
    [arm.py, linear_rail.py, main.py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]
2025-07-05 removed prints
2025-07-07 current idea how playing path can work
2025-07-07 fixed problem with distance zeroing
    [linear_rail.py]
2025-07-07 set the real rail limits
2025-07-07 first working version of play path where it's visualized on the website
    [main.py]
2025-07-07 now init now if it fails
    [main.py]
2025-07-08 new wrapper for theta_1 to hopefully minimize contact with cables
2025-07-08 in theory we should now also keep track of the manual control steps
2025-07-08 hopefully to the cooler grip busy problem
    [main.py]
2025-07-10 updated the move to try to move other joints if one can't and exit only when all three are stuck
    [arm.py]
2025-07-10 fixed little bugs to work with raspi
    [arm.py, linear_rail.py, main.py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]
2025-07-11 again new init logic for both motors
2025-07-11 prevent problems if shared isn't set
    [arm.py]
2025-07-14 deleted preset as they aren't reliable and added storage of current state
2025-07-15 fixed init to not reley on move_by_angle
    [linear_rail.py]
2025-07-15 moved camera position
2025-07-15 corrected file names in desc
    [cooling.py, lamp.py]
2025-07-18 adjusted variables of kinematics after robot has been mounted on the roof
2025-07-18 modified import from helper to kinematics
2025-07-18 modifications to make it work in new enviroment that it still doesn't do
    [sun_helper.py]
2025-07-18 tried to get new sun path working <- still not working
    [kinematics_and_safety.py]
2025-07-18 added blinking if movement is over 10cm
2025-07-18 added printing out on which motor detected metal
2025-07-18 incereased hold time of switch
2025-07-21 fixed the T_base matrix
    [config.py]
2025-07-21 removed magic numbers and now it generated correct finnish path:)
    [sun_helper.py]
2025-07-21 adjusted the fan temps
2025-07-21 added components such as induction sensor and esp
2025-07-22 test blocks for kinematics script
2025-07-22 added motor tests
2025-07-22 Added all the base components cads. Added README to explain the folder contains and manufacturing process. Added pictures:)
    [Axis of rotation.SLDPRT, Axis of rotation.STEP, Base box of the lamp.step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]
2025-07-22 moved manufacturing into documentation folder as it should be there
    [Axis of rotation.SLDPRT, Axis of rotation.STEP, Base box of the lamp.step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]
2025-07-23 init path now takes np.arrays and strings. + required angles now take into account the angles that are reachable by motors
2025-07-23 mainly fixed the angle => shared assigments
    [spinning_joints.py]
2025-07-23 there was typing error in one point
    [test_integration_kinematics.py]
2025-07-23 added printing
2025-07-23 fixed problem of linear class forgetting where it is
    [linear_rail.py]
2025-07-23 fixed return values of to point api + other little silly mistakes
    [main.py]
2025-07-23 added timer reset on first iteration
    [arm.py]
2025-07-23 replaced process terminate with kill
    [main.py]
2025-07-24 copilot fixed the tests
    [run_tests.py]
2025-07-25 fixed problem with sound not playinh
    [arm.py]
